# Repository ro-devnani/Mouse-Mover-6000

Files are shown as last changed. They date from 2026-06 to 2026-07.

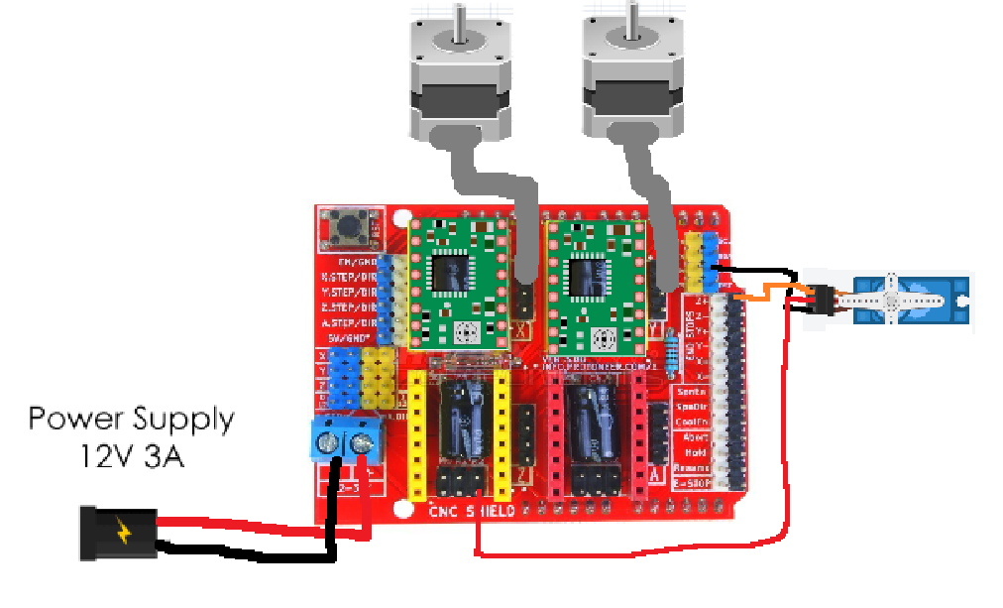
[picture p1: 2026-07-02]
images/mm6000 wiring diagram.png

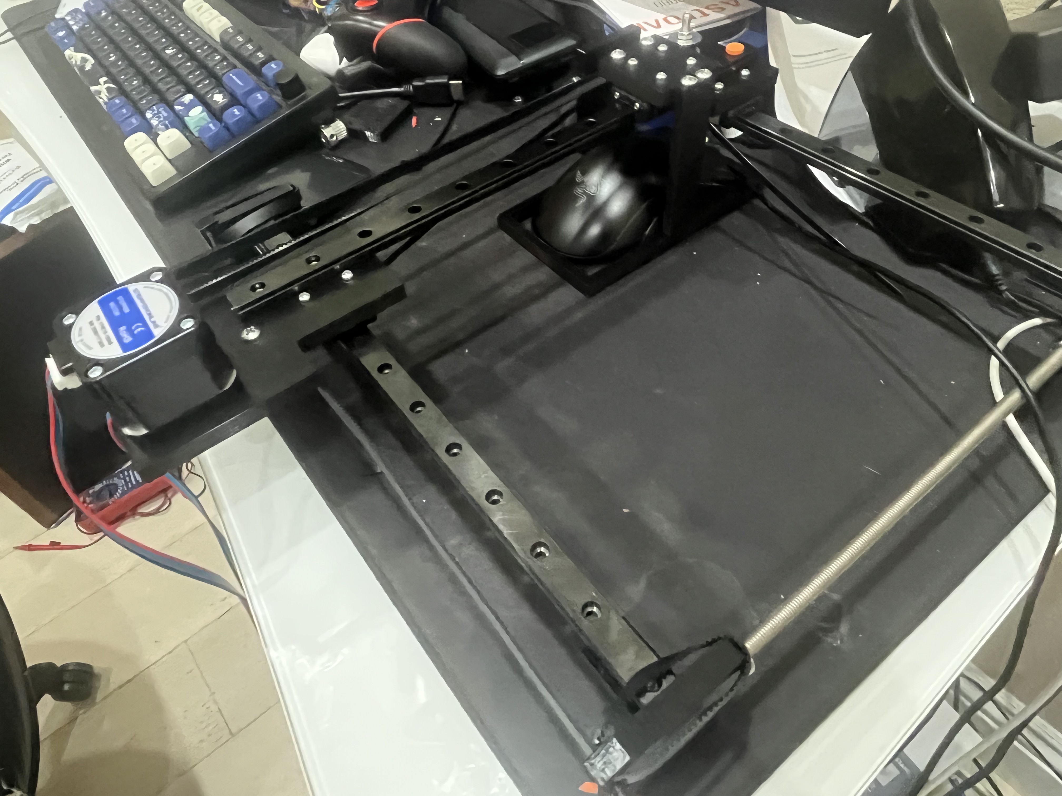
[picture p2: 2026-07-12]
images/IMG_5695.jpg

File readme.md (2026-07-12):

# _Mouse Mover 6000_
An XY plotter based system that can control the movement and clicks of your computer mouse in order to *help* one play shooter based video games by assisting aim.

## _Image Gallery_
mm6 image 1
mm6 image 5
mm6 image 2
mm6 image 3
mm6 image 4
mm6 detection code





## _How it Works_
A color-detection pipeline screenshots the display, finds the on-screen targets, and picks the one nearest the crosshair. The target's pixel offset from screen center is turned into a **velocity command** and streamed continuously over USB to an Arduino Uno + CNC Shield V3 running custom firmware (`code/firmware/mm6000_velocity/`).

The firmware runs the two NEMA 17 steppers at that commanded speed, ramping smoothly between updates instead of stopping every frame — so the mouse glides toward the target rather than moving in choppy hops. Once the crosshair is on the target, the SG90 servo clicks. Then it repeats for the next-nearest target.

> **Note:** the rig originally ran GRBL/G-code; that path was replaced by the custom velocity firmware. The old position-based (move-and-settle) driver is kept for reference in [`archive/stop-start-driver/`](archive/stop-start-driver/).

## _Setup & Run_
Steps to run on a fresh machine.

**1. Firmware** — open `code/firmware/mm6000_velocity/mm6000_velocity.ino` in the Arduino IDE, install the **AccelStepper** and **Servo** libraries, select the Uno + its port, and Upload. The Serial Monitor (115200 baud) should print `mm6000v ready`. Center the carriage before powering — power-on position is the origin.

Machine constants to check in the sketch before flashing:
```
STEPS_PER_MM_X/Y  5.0     // steps per mm — measure on your rig
SOFT_LIMIT_MM     90.0    // ± travel from the power-on origin
ACCEL             4000.0  // slew rate (higher = snappier, too high = jerky)
WATCHDOG_MS       600     // firmware ramps to 0 if the host goes quiet
```

**2. Python** —
```
cd code
pip install -r requirements.txt        # optional: pip install dxcam (faster capture)
```

**3. Configure** `code/aimplotter/config.py` — set `port` (your Arduino COM port), `screen_region`/`screen_center` for your display, and `hsv_lower`/`hsv_upper` for the target color.

**4. Calibrate `gain`** (mm of travel per pixel of view shift) — aim at a target and run:
```
python -m aimplotter.velocity_calibrate
```
Press ENTER; the carriage drives a known velocity for a known time, measures the pixel shift, and prints a suggested `config.gain`. Put that value in `config.py`.

**5. Dry-run** (no hardware, prints commands) then the real run:
```
python -m aimplotter.velocity_main --no-serial
python -m aimplotter.velocity_main
```
Kill switch: **`q`** (global). Teardown zeroes velocity and releases the servo.

**Tuning** (all in `config.py`, no reflash): `kp_v` = chase strength (raise for faster, lower if it overshoots), `max_speed_mm_s` = speed cap, `vel_deadzone_tol_px` = how tightly it centers before clicking. `kff` (feedforward) is off by default — at high frame rates it amplifies detection noise.

## _Bill of Materials_
I will be buying the few materials I need out of pocket, however these are the required components to reproduce.

| Item Name | Quantity | Price (Est. USD) | Link to Buy |
| :--- | :---: | :---: | :--- |
| **MGN12H Linear Guide Rails (300mm length with carriage block)** | 3 | $60.00 ($20.00 each) | [Amazon](https://www.amazon.com/s?k=MGN12H+300mm+linear+rail) / [AliExpress](https://www.aliexpress.com/w/wholesale-MGN12H-300mm.html) |
| **Arduino Uno R3 + CNC Shield V3 + A4988/TMC2208 Driver Bundle** | 1 | $22.00 | [Amazon](https://www.amazon.com/s?k=Arduino+Uno+CNC+Shield+V3+bundle) / [AliExpress](https://www.aliexpress.com/w/wholesale-Arduino+Uno+CNC+Shield+bundle.html) |
| **NEMA 17 Stepper Motor (1.5A - 2.0A)** | 2 | $24.00 ($12.00 each) | [Amazon](https://www.amazon.com/s?k=NEMA+17+stepper+motor) / [Adafruit](https://www.adafruit.com/product/324) |
| **SG90 Micro Servo Motor** | 1 | $4.00 | [Amazon](https://www.amazon.com/s?k=SG90+micro+servo) / [Adafruit](https://www.adafruit.com/product/169) |
| **12V 3A DC Power Supply Adapter** | 1 | $10.00 | [Amazon](https://www.amazon.com/s?k=12v+3a+power+supply+barrel+jack) |
| **GT2 Timing Belt (6mm wide, 2-3 meters)** | 1 | $8.00 | [Amazon](https://www.amazon.com/s?k=GT2+timing+belt+6mm) |
| **GT2 20-Tooth Drive Pulleys (5mm bore)** | 2 | $5.00 ($2.50 each) | [Amazon](https://www.amazon.com/s?k=GT2+20T+pulley+5mm+bore) |
| **GT2 Idler Pulleys (with bearings)** | 2 | $4.00 ($2.00 each) | [Amazon](https://www.amazon.com/s?k=GT2+idler+pulley) |
| **PETG 3D Printer Filament (1kg Spool)** | 1 | $20.00 | [Amazon](https://www.amazon.com/s?k=PETG+filament+1kg) |
| **M3 & M5 Machine Screws and Nuts Assortment Box** | 1 | $13.00 | [Amazon](https://www.amazon.com/s?k=M3+M5+screw+assortment) |
| **Jumper Wires (Female-to-Female)** | 1 | $5.00 | [Amazon](https://www.amazon.com/s?k=female+to+female+jumper+wires) |
| **USB Type-A to Type-B Printer Cable** | 1 | $6.00 | [Amazon](https://www.amazon.com/s?k=usb+a+to+b+cable) |
| **ESTIMATED TOTAL PRICE** | **-** | **$181.00** | **-** |

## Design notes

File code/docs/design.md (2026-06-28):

# mm6000 — Closed-Loop Optical Aim Plotter (Design)

**Date:** 2026-06-28
**Status:** Approved design, pre-implementation

## 1. Summary

Detect neon-blue balls on a 1080p fullscreen Aim Labs feed and drive a GRBL XY
plotter — which carries a physical computer mouse — so the screen-center
crosshair lands on the nearest ball, then fire a servo to click. Because a mouse
produces *relative* input, the system is a **closed-loop proportional-derivative
(PD) visual servo**, not absolute positioning.

## 2. Control Model

The in-game crosshair is fixed at screen center; the view turns based on
accumulated mouse motion. There is no fixed map from plotter position to view
direction, so each frame the loop measures pixel error and commands a relative
move:

```
loop every frame:
  frame  = capture_screen()
  balls  = detect_blue(frame)                 # HSV threshold + contours
  if balls:
      target = nearest_to_center(balls)
      err_px = target.center - screen_center  # (dx, dy) pixels
      if |err_px| <= target.radius:           # crosshair inside hitbox
          click()                             # servo press/release
      else:
          move_mm = pd_control(err_px)        # px -> mm, clamped (glide)
          plotter.jog(move_mm)                # GRBL relative move
  else:
      drift_corrector.tick()                  # reclaim travel during dead time
```

### PD controller
`move = Kp·err + Kd·Δerr + Ki·∫err`, with `Ki = 0` by default (pure PD).
- `Kp` (proportional): main pull toward target; gain < 1 yields a smooth glide.
- `Kd` (derivative): brakes against overshoot on fast flicks.
- `Ki` (integral): available via config for full PID; off by default to avoid
  windup between discrete targets.
- Output is clamped to `MAX_MOVE_MM_PER_FRAME` (rate limit = the "glide").

### GAIN / calibration
`GAIN` = mm of plotter travel per pixel of view error — the number that closes
the loop. Folded into `Kp`. Seeded from a default; refined by `calibrate.py`,
which moves the plotter a known distance and measures the resulting view shift
in pixels.

## 3. Drift Corrector

The loop is relative and closed, so absolute view orientation is irrelevant —
only error-to-target matters. Frames with no ball visible (gaps between Aim Labs
spawns, and just after a click) are "dead time": moving the carriage then turns
the view harmlessly. So after `DRIFT_IDLE_FRAMES` consecutive no-target frames,
the drift corrector gently glides the carriage back toward bed-center (using the
absolute position tracked from accumulated jogs), reclaiming travel headroom.
Normal aiming resumes the moment a ball reappears. The soft-limit guard remains
the hard safety net for the no-lift constraint (see §6).

## 4. Components

Each module has one purpose and a clean interface.

- `capture.py` — fast screen grab via `mss`; returns a BGR frame. Region
  configurable (default full 1920×1080).
- `detector.py` — `detect_blue(frame) -> [Ball(cx, cy, r)]`. HSV range from
  config, morphological denoise, min-area filter.
- `targeting.py` — `nearest_to_center(balls, center) -> Ball`; pixel-error vector.
- `controller.py` — PD/PID math: `error_px -> clamped mm move`; hitbox click
  decision. Pure functions, no I/O.
- `plotter.py` — GRBL serial driver (`pyserial`): connect, `$J=` jog with
  ok-handshake, absolute-position tracking, soft-limit guard, click via
  configurable `PRESS_CMD` / `RELEASE_CMD`.
- `drift.py` — drift corrector (§3).
- `calibrate.py` — interactive pixel-per-mm gain measurement. Optional;
  defaults provided.
- `config.py` — all tunables (HSV range, Kp/Ki/Kd, GAIN, MAX_MOVE_MM_PER_FRAME,
  hitbox tolerance, port, baud=115200, click commands, soft limits, bed-center,
  DRIFT_IDLE_FRAMES, kill key).
- `main.py` — wires the loop; starts kill-switch listener.

## 5. Safety / Kill-Switch

- Global hotkey (default `Q`, via `pynput`) **and** corner-slam detection →
  instant halt: GRBL feed-hold (`!`), servo release, stop loop.
- Soft-limit guard: clamp + warn if a move would exceed configured travel.
- Dry-run mode (`--no-serial`): prints G-code instead of sending, for testing
  detection without hardware.

## 6. Known Constraint

A mouse fixed to a 2D plotter with no Z lift cannot be recentered without
turning the view, so net drift accumulates across many targets. Mitigations:
the drift corrector (§3) reclaims headroom during dead time; the soft-limit
guard pauses for manual re-center if a limit is still reached. Adding a Z servo
to lift the mouse later would enable true unconditional auto-recenter.

## 7. Testing

- Unit: `detector` against synthetic screenshots (blue circles on noise) —
  asserts centroids/radii within tolerance.
- Unit: `controller` math (error→mm, clamping, PD response, hitbox trigger) —
  pure, no hardware.
- Unit: `drift` position tracking and recenter direction.
- Integration: dry-run loop over a recorded clip, asserting the emitted G-code
  sequence.

## 8. Stack

Python 3 · `opencv-python` · `mss` · `numpy` · `pyserial` · `pynput`.
GRBL pre-flashed on the Arduino Uno + CNC Shield v3; servo on the spindle pin,
commanded over the same USB serial link.

## 9. Hardware Assumptions

- Controller: Arduino Uno + CNC Shield v3, GRBL, USB serial @ 115200.
- Click: servo connected to the Arduino, actuated by `PRESS_CMD`/`RELEASE_CMD`
  (default `M3 S1000` / `M5`).
- Steps/mm and exact work-area travel: placeholder defaults in config, to be
  set by the user later.
- Display: single 1080p monitor, Aim Labs fullscreen.

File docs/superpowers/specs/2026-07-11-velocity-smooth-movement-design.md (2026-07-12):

# Velocity-Based Smooth Movement — Design

**Date:** 2026-07-11
**Status:** Approved (design), pending implementation plan
**Branch:** direct-stepper-driver

## Problem

The current aim system moves choppily. Each frame runs a full stop-start cycle:

1. `main.run_loop` computes a clamped **position** delta from the PD controller.
2. `StepperPlotter.jog()` sends `J dx dy feed`; firmware `runMove()` **blocks**,
   running both steppers to their targets and **decelerating to zero every jog**
   (AccelStepper accel/decel curve per move).
3. Python **blocks** waiting for the `ok` ack.
4. `time.sleep(move_settle_s)` lets the view render.
5. Re-capture, repeat.

Motion is therefore move → halt → settle → move → halt. The steppers never carry
momentum between frames, and the mandatory decel-to-zero + settle produces visible
choppiness.

## Goal

Replace discrete position moves with **continuous velocity streaming**. The
controller maps pixel error to a target **velocity** (mm/s) per axis. Firmware runs
the steppers continuously at the commanded speed, non-blocking; each frame only
updates the setpoint. Steppers glide and ramp smoothly toward each new velocity,
never halting between frames. No settle sleep, no blocking ack-wait on motion.

## Non-Goals

- Not replacing the existing stop-start system. It stays intact and runnable as a
  fallback (`controller.py`, `plotter.py`, `main.py`, `mm6000.ino`, `calibrate.py`
  are untouched).
- Not changing detection, tracking, capture, or drift subsystems — reused as-is.
- Not rewriting calibration. `calibrate.py` still measures mm/px gain, which informs
  velocity-tuning defaults but is not on the hot path.

## Architecture

New files, parallel to the existing ones:

```
aimplotter/
  velocity_controller.py     # pixel error -> per-axis velocity (mm/s)
  velocity_plotter.py        # streams V commands, non-blocking
  velocity_main.py           # detect -> aim -> click loop, no settle/no block
firmware/mm6000_velocity/
  mm6000_velocity.ino        # continuous velocity command + watchdog
config.py                    # + velocity section (shared file, new fields)
```

Data flow per frame:

```
capture.grab
  -> detect_blue -> pick target (tracker/nearest)
     target is None      -> set_velocity(0, 0)   (drift reuse deferred)
     error in deadzone    -> set_velocity(0, 0); click if armed
     otherwise            -> v = controller.step(target, dt); set_velocity(v)
```

## Component 1 — Firmware (`mm6000_velocity.ino`)

Same CNC Shield V3 pin map, servo, and `!` abort semantics as `mm6000.ino`.

**Protocol:**

| Command | Meaning | Ack |
|---|---|---|
| `V <vx_mm_s> <vy_mm_s>\n` | set target velocity per axis | **none** (fire-and-forget) |
| `S <angle>\n` | servo angle (click) | `ok` |
| `!` | abort: zero target velocity | none |

`V` intentionally does **not** ack. Streaming velocity at frame rate cannot afford a
blocking round-trip per update; the whole point is to remove the ack-wait stall.

**Control loop (non-blocking, tight):**

- Store `targetSpeedX`, `targetSpeedY` (steps/s), set by the last `V`.
- Each `loop()` iteration:
  1. Drain any available serial bytes into the line buffer; parse complete lines.
  2. **Slew** `currentSpeedX/Y` toward `targetSpeedX/Y`, limited to `ACCEL * dt`
     steps/s per tick. Bounded acceleration = smooth ramps, no velocity-step jerk
     even if the setpoint jumps.
  3. `setSpeed(currentSpeed)` then `runSpeed()` for each axis (constant-speed step
     generation; no AccelStepper decel-to-target because there is no target).
- `dt` measured from `micros()` between iterations.

**Watchdog:** if no `V` command has arrived within `WATCHDOG_MS` (~200 ms), force
`targetSpeed = 0` on both axes. The slew still applies, so the rig ramps down smoothly
rather than snapping. Protects against a dead/unplugged host leaving the rig running.

**Soft limits (authoritative in firmware):** track `currentPosition()` in steps.
Convert `soft_limit_mm` to steps at compile/config time. Before `runSpeed()`, if an
axis is at or beyond its ± limit **and** the commanded velocity points further out,
zero that axis's speed (that axis only; the other keeps moving). Firmware is the
final authority on limits; Python keeps an estimate only for logging.

## Component 2 — Velocity controller (`velocity_controller.py`)

Pure function of pixel error + target motion; holds minimal state for feedforward.

```
v_axis = kp_v * error_px[axis] + kff * target_velocity_px_s[axis]
```

- `error_px` = target center − screen center (same sign convention as current
  `error_vector`; invert_x / invert_y applied as today).
- `target_velocity_px_s` = (target pixel position − previous target pixel position)
  / dt. Feedforward term: keeps the crosshair with a moving target instead of always
  chasing from behind.
- **Deadzone:** if `hypot(error) <= radius + vel_deadzone_tol_px`, output `(0, 0)`
  and signal "on target" so the caller can hold and arm/fire the click.
- **Clamp:** limit `hypot(vx, vy)` to `max_speed_mm_s` (preserve direction).
- **State:** previous target pixel position + previous timestamp. `reset()` clears
  it (call when the locked target changes, so feedforward does not jump across a
  target switch). If no previous sample, feedforward is 0 for that frame.

Units: `kp_v` is mm/s of commanded speed per pixel of error. `kff` is dimensionless
scaling on target pixel velocity converted to mm/s via the calibrated mm/px gain
(so `kff = 1.0` means "match the target's apparent speed"). Default `kff` starts
conservative.

## Component 3 — Velocity plotter (`velocity_plotter.py`)

```
set_velocity(vx_mm_s, vy_mm_s) -> None   # sends "V vx vy\n", NO ack-wait
click() -> None                          # S press, dwell, S release (ack)
safe_stop() -> None                      # S release, then "!"
feed_hold() -> None                      # "!"
position (property) -> (x, y)            # estimate from integrated velocity*dt
```

- `set_velocity` writes and returns immediately — this is the streaming hot path.
- `click`/`safe_stop` reuse the acked `S` path from the existing plotter design.
- Position estimate is for debug/logging only; firmware enforces limits. Plotter may
  still pre-clamp the commanded velocity toward a limit as a courtesy, but is not the
  authority.

## Component 4 — Velocity main (`velocity_main.py`)

Mirrors `main.run_loop` structure minus the blocking bits:

- No `move_settle_s` sleep. No per-move ack stall. Loop cadence = capture cadence.
- Compute `dt` between frames (for controller feedforward + firmware watchdog health).
- Same kill-switch listener and `_PrintPlotter` dry-run (prints `V`/`CLICK`).
- On target-in-deadzone: `set_velocity(0, 0)`; `click()` if armed; then hold (no jog).
  Re-arm when the crosshair leaves the target, same as current `armed` logic.
- On no target: `set_velocity(0, 0)`. Drift reuse is optional and deferred; the
  velocity system's baseline is "stop when nothing to track."
- On teardown (`finally`): `set_velocity(0, 0)` then `safe_stop()`.

## Component 5 — Config additions

Append a velocity section to the existing `Config` dataclass (reusing detection,
capture, serial, soft-limit, servo fields). New fields:

| Field | Purpose | Starting default |
|---|---|---|
| `kp_v` | mm/s commanded per px error | tune (e.g. 0.05) |
| `kff` | feedforward scale on target motion | 0.5 |
| `max_speed_mm_s` | velocity magnitude clamp | e.g. 40 |
| `vel_watchdog_ms` | host-side note; firmware constant mirrors it | 200 |
| `vel_deadzone_tol_px` | hold zone = radius + this | 6.0 |

Existing stop-start fields (`gain`, `kp/ki/kd`, `max_move_mm`, `move_settle_s`) are
left untouched so the old system still runs.

## Error Handling & Safety

- **Firmware watchdog** ramps to zero if the host stops streaming — primary safety net.
- **`!` abort** and the kill-switch key remain wired through.
- **Soft limits** enforced in firmware (authoritative), estimated in Python.
- Malformed `V` line: firmware ignores (no target change) rather than faulting; the
  watchdog covers a persistent parse failure.

## Testing

- **Controller** — pure/unit testable: feed synthetic error + target-motion sequences,
  assert velocity output, deadzone zeroing, clamp magnitude, feedforward reset on
  target switch. No hardware.
- **Plotter** — inject a fake serial object; assert exact `V`/`S`/`!` bytes and that
  `set_velocity` does not block on a read.
- **Main loop** — reuse the existing `run_loop` test harness pattern (frame source
  callable + fake plotter), assert the action log: `vel`, `hold`, `click`, `idle`.
- **Firmware** — manual/bench: confirm continuous motion, smooth ramp on setpoint
  jumps, watchdog stop on host silence, per-axis limit clamp.

## Open Questions (resolve during planning)

- Exact starting values for `kp_v` / `kff` / `max_speed_mm_s` (bench-tune; spec gives
  conservative seeds).
- Whether to reuse `DriftCorrector` in velocity mode or keep "stop when idle" only.
```

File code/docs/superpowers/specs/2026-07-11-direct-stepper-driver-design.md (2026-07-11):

# Direct Stepper Driver — Replace GRBL with Custom Firmware (Design)

**Date:** 2026-07-11
**Status:** Approved design, pre-implementation

## 1. Summary

Remove GRBL from the Arduino Uno. Use the CNC Shield V3 as a passive breakout
board and run custom firmware that drives the A4988 STEP/DIR pins directly and
actuates the SG90 click servo. The PC talks to the firmware over a simple
line-based serial protocol.

The existing Python control stack (screen capture → blue detection → nearest
target → PD controller → relative jog → servo click, plus drift corrector and
kill-switch) is unchanged in behaviour. Only the plotter **driver internals**
and a few `config.py` fields change, because the Python↔hardware seam keeps the
same shape it has today: send a line, wait for `ok`.

## 2. Motivation

GRBL adds a firmware layer whose CNC semantics (jog queue, laser/spindle modes,
homing, `$$` config) are overhead for this project and introduced real setup
snags — notably driving a hobby servo off the ~1 kHz spindle PWM pin. Owning the
firmware lets us drive the servo with the `Servo` library at the correct 50 Hz
and keep the motion model as simple as the task needs (relative jogs, no
homing, no endstops).

## 3. Architecture

Two halves connected by a serial line protocol. The seam is identical to the
current design, so the Python loop above the driver is untouched.

```
PC (Python)                              Arduino Uno + CNC Shield V3
-----------                              ---------------------------
StepperPlotter.jog(dx,dy)  --"J dx dy feed\n"-->  parse, mm->steps,
                                                  AccelStepper run, then
                           <------"ok\n"--------  ack
StepperPlotter.click()     --"S 60\n"--------->   servo.write(60), ack
                              (dwell)
                           --"S 90\n"--------->   servo.write(90), ack
StepperPlotter.safe_stop() --"!"------------->    abort motion (no ack)
```

### 3.1 Firmware — `firmware/mm6000/mm6000.ino`

- **CNC Shield V3 is a passive breakout.** Standard GRBL pin map:
  - X: STEP=D2, DIR=D5
  - Y: STEP=D3, DIR=D6
  - Driver ENABLE=D8 (active low; pulled LOW at boot to energize drivers)
  - Servo signal=D11
- **Libraries:** `AccelStepper` (one instance per axis) and `Servo`.
- **Compile-time constants (`#define`):** `STEPS_PER_MM_X`, `STEPS_PER_MM_Y`,
  `ACCEL` (steps/s²), `DEFAULT_SPEED` (steps/s fallback). `steps/mm` lives here,
  measured on the built machine and baked in; changing microstepping means a
  reflash.
- **Motion:** each axis is an `AccelStepper` in `DRIVER` mode. A move sets both
  axes' `maxSpeed` from the requested feed, calls `moveTo` (relative target in
  steps), then loops `run()` on both until both reach target. Acceleration is
  applied per axis. The two axes are not guaranteed to finish the same instant;
  for the ≤5 mm per-frame jogs the skew is negligible (accepted trade-off — the
  coordinated alternative, `MultiStepper`, cannot do acceleration).
- **Abort:** the run loop polls `Serial.available()` every iteration. If a `!`
  byte arrives mid-move, it stops both steppers immediately and exits the move.
  This keeps kill-switch latency low even though normal moves block.
- **Boot:** set ENABLE low, attach servo, move servo to release angle, print a
  ready banner. Then serve the command loop.

### 3.2 Serial protocol

- 115200 baud, `\n`-terminated ASCII lines. Every completed command replies
  `ok\n`. Unknown commands reply `err\n`.

| PC → Arduino | Meaning | Reply |
| :--- | :--- | :--- |
| `J <dx_mm> <dy_mm> <feed_mm_min>` | Relative move. Firmware converts mm→steps, sets max speed from feed, runs to completion. | `ok` after move done |
| `S <angle>` | Set servo to `<angle>` degrees (0–180). | `ok` |
| `!` (single byte, **no** newline) | Realtime abort — stop steppers now. | none |

Design intent: mirror the current "send line, wait for `ok`" handshake so
`StepperPlotter._send` is the same shape as today's `GRBLPlotter._send`.

### 3.3 Python — `aimplotter/plotter.py`

Rename `GRBLPlotter` → `StepperPlotter`. Identical public surface:

- `__init__(serial_obj, soft_limit_mm, bed_center_mm, press_angle,
  release_angle, click_dwell_s, feed_mm_min=3000, sleep_fn=time.sleep)`
- `position -> tuple[float, float]` — unchanged (tracked from accumulated jogs).
- `jog(dx_mm, dy_mm) -> bool` — keeps the existing soft-limit `_clamp` (the only
  travel guard; no endstops are wired). Sends `J <real_dx> <real_dy> <feed>\n`,
  waits for `ok`, updates tracked position, returns `False` if clamped.
- `click()` — sends `S <press_angle>\n`, sleeps `click_dwell_s`, sends
  `S <release_angle>\n`.
- `feed_hold()` / `safe_stop()` — write the raw `!` byte.

`_send` writes the line, then reads lines until `ok` (raising `RuntimeError` on
`err`), matching the current ok-handshake loop.

### 3.4 Config — `aimplotter/config.py`

- Remove `press_cmd`, `release_cmd`.
- Add `press_angle: int = 60`, `release_angle: int = 90` (tune to servo horn).
- `port`, `baud` (115200), soft limits, everything else unchanged.
- `steps/mm` is **not** in Python config — it lives in firmware.

### 3.5 Wiring — `main.py`, `calibrate.py`

Only the `StepperPlotter` constructor call changes: pass `config.press_angle` /
`config.release_angle` instead of the old M-code strings. Loop, controller,
drift, capture, kill-switch untouched.

## 4. Data Flow (unchanged above the driver)

`capture → detect_blue → nearest_to_center → PDController.step → StepperPlotter.jog`
per frame; on hitbox hit → `StepperPlotter.click`; on dead frames →
`DriftCorrector.tick → StepperPlotter.jog`. The GAIN (mm-per-pixel) calibration
via `calibrate.py` is unaffected — it still jogs a known mm and measures pixel
shift.

## 5. Error Handling & Safety

- **Soft-limit clamp** in `jog()` stays the sole travel guard (no endstops).
- **Kill switch:** `q` stops the Python loop; `finally` calls `safe_stop()` →
  `!`. Firmware aborts mid-move on `!`.
- **Serial errors:** `_send` raises `RuntimeError` on `err` reply; `main.py`
  swallows exceptions in the `finally` cleanup path as today.
- **Boot settle:** `main.py` keeps the ~2 s sleep after opening serial so the
  Uno finishes resetting before the first command.

## 6. Testing

- `tests/test_plotter.py` rewritten against a `FakeSerial` that acks `ok\n`:
  - `jog` sends a line starting `J ` with correct `X`/`Y`… → assert on the `J`
    payload and tracked position (adapt existing format assertions).
  - `jog` clamps to soft limits and returns `False` beyond travel (unchanged
    logic, unchanged assertion).
  - `click` sends `S <press_angle>` then `S <release_angle>`.
  - `safe_stop`/`feed_hold` write the raw `!` byte.
- All other unit tests (detector, targeting, controller, drift) and the
  integration test are unaffected — they never touch the serial protocol.
- Firmware is verified manually on hardware (jog a known distance, confirm servo
  press/release); no automated firmware test.

## 7. Files Touched

- Create: `firmware/mm6000/mm6000.ino`
- Edit: `aimplotter/plotter.py` (class rename + new protocol)
- Edit: `aimplotter/config.py` (angles replace M-codes)
- Edit: `aimplotter/main.py` (constructor args)
- Edit: `aimplotter/calibrate.py` (constructor args)
- Edit: `tests/test_plotter.py` (protocol assertions)

## 8. Out of Scope

- Homing / endstops (none wired).
- Coordinated same-instant multi-axis finish (accepted skew).
- Runtime-configurable steps/mm (reflash instead).
- Z-lift servo for true auto-recenter (future, as noted in prior design §6).

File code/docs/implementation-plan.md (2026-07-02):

# Closed-Loop Optical Aim Plotter Implementation Plan

**Goal:** Detect neon-blue balls on a 1080p fullscreen Aim Labs feed and drive a GRBL XY plotter (carrying a physical mouse) via a closed-loop PD visual servo so the screen-center crosshair lands on the nearest ball and clicks.

**Architecture:** A per-frame loop: capture screen → HSV-detect balls → pick nearest to center → PD controller turns pixel error into a clamped relative mm jog → GRBL serial driver moves the plotter → repeat until the crosshair is inside the ball's hitbox → servo click. A drift corrector reclaims plotter travel during no-target frames. Pure logic modules (detector, targeting, controller, drift) are hardware-free and unit-tested; the plotter driver is tested against a fake serial port.

**Tech Stack:** Python 3 · `opencv-python` · `numpy` · `mss` · `pyserial` · `pynput` · `pytest`

## Global Constraints

- Python 3.10+ (uses `X | None` typing, `match` optional).
- Target display: single 1920×1080 monitor; crosshair fixed at screen center `(960, 540)`.
- GRBL on Arduino Uno + CNC Shield v3, USB serial @ **115200** baud.
- Plotter moves are **relative** (`G91`) via GRBL jog (`$J=`); each line waits for `ok`.
- Click is firmware-agnostic: configurable `PRESS_CMD` / `RELEASE_CMD` strings (default `M3 S1000` / `M5`).
- All tunables live in `config.py`; no magic numbers in logic modules — pass config values in as parameters (keep logic modules pure).
- Distances in millimetres (mm); pixel errors in pixels (px). `GAIN` = mm per px.
- Steps/mm and exact work-area travel are user-set later; use placeholder defaults.
- Every logic module is hardware-free and importable without a serial port attached.

---

## File Structure

```
mm6000/
├── requirements.txt
├── aimplotter/
│   ├── __init__.py
│   ├── config.py          # Config dataclass, all tunables + defaults
│   ├── models.py          # Ball dataclass
│   ├── detector.py        # detect_blue()
│   ├── targeting.py       # nearest_to_center(), error_vector()
│   ├── controller.py      # PDController (PD/PID), on_target()
│   ├── plotter.py         # GRBLPlotter serial driver
│   ├── drift.py           # DriftCorrector
│   ├── capture.py         # ScreenCapture (mss)
│   ├── calibrate.py       # interactive GAIN measurement (script)
│   └── main.py            # loop wiring + kill-switch + dry-run
└── tests/
    ├── test_detector.py
    ├── test_targeting.py
    ├── test_controller.py
    ├── test_plotter.py
    ├── test_drift.py
    └── test_integration.py
```

---

### Task 1: Project scaffold, config, and Ball model

**Files:**
- Create: `requirements.txt`
- Create: `aimplotter/__init__.py`
- Create: `aimplotter/config.py`
- Create: `aimplotter/models.py`
- Test: `tests/test_targeting.py` (placeholder import test here; real tests in Task 3)

**Interfaces:**
- Produces: `Ball(cx: float, cy: float, r: float)` dataclass with `center -> tuple[float, float]`.
- Produces: `Config` dataclass with fields used by all later tasks (see code).

- [ ] **Step 1: Write `requirements.txt`**

```
opencv-python>=4.8
numpy>=1.24
mss>=9.0
pyserial>=3.5
pynput>=1.7
pytest>=7.4
```

- [ ] **Step 2: Write `aimplotter/__init__.py`** (empty file)

```python
```

- [ ] **Step 3: Write the failing test for the models**

`tests/test_targeting.py`:
```python
from aimplotter.models import Ball
from aimplotter.config import Config

def test_ball_center():
    b = Ball(cx=10.0, cy=20.0, r=5.0)
    assert b.center == (10.0, 20.0)

def test_config_defaults():
    c = Config()
    assert c.baud == 115200
    assert c.screen_center == (960, 540)
    assert c.ki == 0.0  # pure PD by default
```

- [ ] **Step 4: Run test to verify it fails**

Run: `python -m pytest tests/test_targeting.py -v`
Expected: FAIL with `ModuleNotFoundError: No module named 'aimplotter.models'`

- [ ] **Step 5: Write `aimplotter/models.py`**

```python
from dataclasses import dataclass

@dataclass
class Ball:
    cx: float
    cy: float
    r: float

    @property
    def center(self) -> tuple[float, float]:
        return (self.cx, self.cy)
```

- [ ] **Step 6: Write `aimplotter/config.py`**

```python
from dataclasses import dataclass, field

@dataclass
class Config:
    # --- display ---
    screen_region: dict = field(
        default_factory=lambda: {"top": 0, "left": 0, "width": 1920, "height": 1080}
    )
    screen_center: tuple[int, int] = (960, 540)

    # --- detection (neon blue in HSV; OpenCV H is 0-179) ---
    hsv_lower: tuple[int, int, int] = (90, 120, 120)
    hsv_upper: tuple[int, int, int] = (120, 255, 255)
    min_area_px: float = 80.0

    # --- control ---
    gain: float = 0.03            # mm of plotter travel per px of error
    kp: float = 1.0               # multiplies gain
    ki: float = 0.0               # 0 = pure PD
    kd: float = 0.2
    max_move_mm: float = 5.0      # clamp per frame -> "glide"
    hitbox_tol_px: float = 6.0    # extra slack added to ball radius

    # --- plotter / serial ---
    port: str = "COM3"
    baud: int = 115200
    press_cmd: str = "M3 S1000"
    release_cmd: str = "M5"
    click_dwell_s: float = 0.04

    # --- soft limits (mm), bed center is origin reference ---
    soft_limit_mm: float = 100.0  # +/- travel from start in X and Y
    bed_center_mm: tuple[float, float] = (0.0, 0.0)

    # --- drift corrector ---
    drift_idle_frames: int = 8
    drift_step_mm: float = 1.0

    # --- safety ---
    kill_key: str = "q"
```

- [ ] **Step 7: Run tests to verify they pass**

Run: `python -m pytest tests/test_targeting.py -v`
Expected: PASS (2 passed)

- [ ] **Step 8: Commit**

```bash
git add requirements.txt aimplotter/__init__.py aimplotter/models.py aimplotter/config.py tests/test_targeting.py
git commit -m "feat: project scaffold, Config, and Ball model"
```

---

### Task 2: Blue-ball detector

**Files:**
- Create: `aimplotter/detector.py`
- Test: `tests/test_detector.py`

**Interfaces:**
- Consumes: `Ball` (Task 1).
- Produces: `detect_blue(frame, hsv_lower, hsv_upper, min_area) -> list[Ball]` where `frame` is an HxWx3 BGR `numpy.uint8` array; returns balls sorted by descending area.

- [ ] **Step 1: Write the failing test**

`tests/test_detector.py`:
```python
import numpy as np
import cv2
from aimplotter.detector import detect_blue
from aimplotter.config import Config

C = Config()

def _frame_with_blue_circle(cx, cy, r, size=(1080, 1920)):
    frame = np.zeros((size[0], size[1], 3), dtype=np.uint8)
    # neon blue in BGR is high B, low G/R
    cv2.circle(frame, (cx, cy), r, (255, 80, 0), -1)
    return frame

def test_detects_single_ball_center():
    frame = _frame_with_blue_circle(960, 540, 30)
    balls = detect_blue(frame, C.hsv_lower, C.hsv_upper, C.min_area_px)
    assert len(balls) == 1
    assert abs(balls[0].cx - 960) <= 3
    assert abs(balls[0].cy - 540) <= 3
    assert balls[0].r > 20

def test_ignores_small_noise():
    frame = _frame_with_blue_circle(100, 100, 2)
    balls = detect_blue(frame, C.hsv_lower, C.hsv_upper, C.min_area_px)
    assert balls == []

def test_detects_multiple_sorted_by_area():
    frame = _frame_with_blue_circle(300, 300, 20)
    cv2.circle(frame, (1500, 800), 40, (255, 80, 0), -1)
    balls = detect_blue(frame, C.hsv_lower, C.hsv_upper, C.min_area_px)
    assert len(balls) == 2
    assert balls[0].r >= balls[1].r  # largest first
```

- [ ] **Step 2: Run test to verify it fails**

Run: `python -m pytest tests/test_detector.py -v`
Expected: FAIL with `ModuleNotFoundError: No module named 'aimplotter.detector'`

- [ ] **Step 3: Write `aimplotter/detector.py`**

```python
import cv2
import numpy as np
from aimplotter.models import Ball

def detect_blue(frame, hsv_lower, hsv_upper, min_area) -> list[Ball]:
    """Find neon-blue blobs in a BGR frame, return Balls sorted largest-first."""
    hsv = cv2.cvtColor(frame, cv2.COLOR_BGR2HSV)
    mask = cv2.inRange(hsv, np.array(hsv_lower), np.array(hsv_upper))
    kernel = np.ones((3, 3), np.uint8)
    mask = cv2.morphologyEx(mask, cv2.MORPH_OPEN, kernel)
    mask = cv2.morphologyEx(mask, cv2.MORPH_CLOSE, kernel)

    contours, _ = cv2.findContours(mask, cv2.RETR_EXTERNAL, cv2.CHAIN_APPROX_SIMPLE)
    balls: list[Ball] = []
    for c in contours:
        area = cv2.contourArea(c)
        if area < min_area:
            continue
        (x, y), r = cv2.minEnclosingCircle(c)
        balls.append(Ball(cx=float(x), cy=float(y), r=float(r)))

    balls.sort(key=lambda b: b.r, reverse=True)
    return balls
```

- [ ] **Step 4: Run tests to verify they pass**

Run: `python -m pytest tests/test_detector.py -v`
Expected: PASS (3 passed)

- [ ] **Step 5: Commit**

```bash
git add aimplotter/detector.py tests/test_detector.py
git commit -m "feat: HSV neon-blue ball detector"
```

---

### Task 3: Targeting

**Files:**
- Create: `aimplotter/targeting.py`
- Test: `tests/test_targeting.py` (extend)

**Interfaces:**
- Consumes: `Ball` (Task 1).
- Produces:
  - `nearest_to_center(balls, center) -> Ball | None`
  - `error_vector(ball, center) -> tuple[float, float]` returning `(dx, dy)` = ball − center.

- [ ] **Step 1: Write the failing tests** (append to `tests/test_targeting.py`)

```python
from aimplotter.targeting import nearest_to_center, error_vector

def test_nearest_to_center_picks_closest():
    near = Ball(cx=965.0, cy=545.0, r=10.0)
    far = Ball(cx=200.0, cy=200.0, r=10.0)
    assert nearest_to_center([far, near], (960, 540)) is near

def test_nearest_to_center_empty_returns_none():
    assert nearest_to_center([], (960, 540)) is None

def test_error_vector():
    b = Ball(cx=1000.0, cy=500.0, r=10.0)
    assert error_vector(b, (960, 540)) == (40.0, -40.0)
```

- [ ] **Step 2: Run tests to verify they fail**

Run: `python -m pytest tests/test_targeting.py -v`
Expected: FAIL with `ModuleNotFoundError: No module named 'aimplotter.targeting'`

- [ ] **Step 3: Write `aimplotter/targeting.py`**

```python
import math
from aimplotter.models import Ball

def error_vector(ball: Ball, center) -> tuple[float, float]:
    return (ball.cx - center[0], ball.cy - center[1])

def nearest_to_center(balls, center) -> Ball | None:
    if not balls:
        return None
    return min(
        balls,
        key=lambda b: math.hypot(b.cx - center[0], b.cy - center[1]),
    )
```

- [ ] **Step 4: Run tests to verify they pass**

Run: `python -m pytest tests/test_targeting.py -v`
Expected: PASS (5 passed)

- [ ] **Step 5: Commit**

```bash
git add aimplotter/targeting.py tests/test_targeting.py
git commit -m "feat: nearest-target selection and error vector"
```

---

### Task 4: PD/PID controller

**Files:**
- Create: `aimplotter/controller.py`
- Test: `tests/test_controller.py`

**Interfaces:**
- Produces:
  - `PDController(gain, kp, ki, kd, max_move_mm)` with `step(err_px) -> tuple[float, float]` (clamped mm move) and `reset()`.
  - `on_target(err_px, radius, tol) -> bool` — True when the crosshair is inside the hitbox.
- Consumes: config scalars (Task 1).

Note: `step` takes `err_px=(dx, dy)`; output mm has the **same sign** as error (move toward target). Magnitude clamped to `max_move_mm`. Derivative uses change in error between calls.

- [ ] **Step 1: Write the failing tests**

`tests/test_controller.py`:
```python
import math
from aimplotter.controller import PDController, on_target

def test_proportional_move_toward_target():
    c = PDController(gain=0.03, kp=1.0, ki=0.0, kd=0.0, max_move_mm=5.0)
    mx, my = c.step((100.0, -100.0))
    assert mx > 0 and my < 0                 # same direction as error
    assert math.isclose(mx, 3.0, abs_tol=1e-6)   # 100 * 0.03 * 1.0

def test_move_is_clamped():
    c = PDController(gain=1.0, kp=1.0, ki=0.0, kd=0.0, max_move_mm=5.0)
    mx, my = c.step((100.0, 0.0))
    assert math.isclose(math.hypot(mx, my), 5.0, abs_tol=1e-6)

def test_derivative_damps_on_growing_error():
    c = PDController(gain=0.0, kp=0.0, ki=0.0, kd=0.5, max_move_mm=100.0)
    c.step((10.0, 0.0))            # prev err set
    mx, _ = c.step((30.0, 0.0))    # delta = 20 -> 0.5*20 = 10
    assert math.isclose(mx, 10.0, abs_tol=1e-6)

def test_reset_clears_state():
    c = PDController(gain=0.0, kp=0.0, ki=0.0, kd=0.5, max_move_mm=100.0)
    c.step((10.0, 0.0))
    c.reset()
    mx, _ = c.step((10.0, 0.0))    # treated as first sample, delta=0
    assert math.isclose(mx, 0.0, abs_tol=1e-6)

def test_on_target_inside_hitbox():
    assert on_target((3.0, 0.0), radius=10.0, tol=2.0) is True
    assert on_target((20.0, 0.0), radius=10.0, tol=2.0) is False
```

- [ ] **Step 2: Run tests to verify they fail**

Run: `python -m pytest tests/test_controller.py -v`
Expected: FAIL with `ModuleNotFoundError: No module named 'aimplotter.controller'`

- [ ] **Step 3: Write `aimplotter/controller.py`**

```python
import math

class PDController:
    """Turns a pixel-error vector into a clamped relative mm move.

    Pure PD by default (ki=0); set ki>0 for full PID. State held between
    step() calls for derivative/integral terms; reset() between targets.
    """

    def __init__(self, gain, kp, ki, kd, max_move_mm):
        self.gain = gain
        self.kp = kp
        self.ki = ki
        self.kd = kd
        self.max_move_mm = max_move_mm
        self.reset()

    def reset(self) -> None:
        self._prev = None
        self._integral = [0.0, 0.0]

    def step(self, err_px) -> tuple[float, float]:
        out = [0.0, 0.0]
        for i in range(2):
            e = err_px[i]
            d = 0.0 if self._prev is None else (e - self._prev[i])
            self._integral[i] += e
            term = self.kp * e + self.kd * d + self.ki * self._integral[i]
            out[i] = self.gain * term
        self._prev = (err_px[0], err_px[1])

        mag = math.hypot(out[0], out[1])
        if mag > self.max_move_mm and mag > 0:
            scale = self.max_move_mm / mag
            out[0] *= scale
            out[1] *= scale
        return (out[0], out[1])

def on_target(err_px, radius, tol) -> bool:
    return math.hypot(err_px[0], err_px[1]) <= (radius + tol)
```

- [ ] **Step 4: Run tests to verify they pass**

Run: `python -m pytest tests/test_controller.py -v`
Expected: PASS (5 passed)

- [ ] **Step 5: Commit**

```bash
git add aimplotter/controller.py tests/test_controller.py
git commit -m "feat: PD/PID controller and hitbox check"
```

---

### Task 5: GRBL serial plotter driver

**Files:**
- Create: `aimplotter/plotter.py`
- Test: `tests/test_plotter.py`

**Interfaces:**
- Produces: `GRBLPlotter(serial_obj, soft_limit_mm, bed_center_mm, press_cmd, release_cmd, click_dwell_s)` with:
  - `jog(dx_mm, dy_mm) -> bool` — sends `$J=G91 G21 X.. Y.. F..`, waits `ok`, updates tracked position, clamps to soft limits (returns `False` if clamped).
  - `click()` — sends press_cmd, dwell, release_cmd.
  - `feed_hold()` — sends `!`.
  - `position -> tuple[float, float]` — tracked absolute mm from start.
  - `sleep_fn` injectable (defaults to `time.sleep`) so tests don't actually wait.
- The serial object must expose `write(bytes)` and `readline() -> bytes`. Tests pass a `FakeSerial` that returns `b"ok\n"`.

- [ ] **Step 1: Write the failing tests**

`tests/test_plotter.py`:
```python
from aimplotter.plotter import GRBLPlotter

class FakeSerial:
    def __init__(self):
        self.written = []
        self._lines = []

    def write(self, data):
        self.written.append(data.decode())
        self._lines.append(b"ok\n")  # GRBL acks every line

    def readline(self):
        return self._lines.pop(0) if self._lines else b"ok\n"

def _plotter():
    return GRBLPlotter(
        FakeSerial(), soft_limit_mm=10.0, bed_center_mm=(0.0, 0.0),
        press_cmd="M3 S1000", release_cmd="M5", click_dwell_s=0.0,
        sleep_fn=lambda s: None,
    )

def test_jog_sends_relative_gcode_and_tracks_position():
    p = _plotter()
    ok = p.jog(2.0, -1.5)
    assert ok is True
    assert p.position == (2.0, -1.5)
    sent = p.serial.written[-1]
    assert sent.startswith("$J=G91 G21")
    assert "X2.000" in sent and "Y-1.500" in sent

def test_jog_clamps_to_soft_limits():
    p = _plotter()
    ok = p.jog(50.0, 0.0)            # beyond +10 limit
    assert ok is False
    assert p.position[0] == 10.0     # clamped to limit

def test_click_sends_press_then_release():
    p = _plotter()
    p.click()
    assert "M3 S1000" in p.serial.written[-2]
    assert "M5" in p.serial.written[-1]

def test_feed_hold_sends_bang():
    p = _plotter()
    p.feed_hold()
    assert p.serial.written[-1] == "!"
```

- [ ] **Step 2: Run tests to verify they fail**

Run: `python -m pytest tests/test_plotter.py -v`
Expected: FAIL with `ModuleNotFoundError: No module named 'aimplotter.plotter'`

- [ ] **Step 3: Write `aimplotter/plotter.py`**

```python
import time

class GRBLPlotter:
    def __init__(self, serial_obj, soft_limit_mm, bed_center_mm,
                 press_cmd, release_cmd, click_dwell_s,
                 feed_mm_min=3000, sleep_fn=time.sleep):
        self.serial = serial_obj
        self.soft_limit_mm = soft_limit_mm
        self.center = bed_center_mm
        self.press_cmd = press_cmd
        self.release_cmd = release_cmd
        self.click_dwell_s = click_dwell_s
        self.feed_mm_min = feed_mm_min
        self._sleep = sleep_fn
        self._x, self._y = bed_center_mm

    @property
    def position(self) -> tuple[float, float]:
        return (self._x, self._y)

    def _send(self, line: str) -> None:
        self.serial.write(line.encode() if not line.endswith("\n")
                          else line.encode())
        self.serial.readline()  # wait for GRBL 'ok'

    def _clamp(self, target, axis_center):
        lo = axis_center - self.soft_limit_mm
        hi = axis_center + self.soft_limit_mm
        if target < lo:
            return lo, True
        if target > hi:
            return hi, True
        return target, False

    def jog(self, dx_mm, dy_mm) -> bool:
        nx, cx_clamped = self._clamp(self._x + dx_mm, self.center[0])
        ny, cy_clamped = self._clamp(self._y + dy_mm, self.center[1])
        real_dx = nx - self._x
        real_dy = ny - self._y
        line = (f"$J=G91 G21 X{real_dx:.3f} Y{real_dy:.3f} "
                f"F{self.feed_mm_min}\n")
        self._send(line)
        self._x, self._y = nx, ny
        return not (cx_clamped or cy_clamped)

    def click(self) -> None:
        self._send(self.press_cmd + "\n")
        self._sleep(self.click_dwell_s)
        self._send(self.release_cmd + "\n")

    def feed_hold(self) -> None:
        self.serial.write(b"!")  # realtime, no newline, no ok
```

Note: `feed_hold` writes the raw `!` byte (GRBL realtime command — no newline, no `ok`). The test asserts `written[-1] == "!"`.

- [ ] **Step 4: Run tests to verify they pass**

Run: `python -m pytest tests/test_plotter.py -v`
Expected: PASS (4 passed)

- [ ] **Step 5: Commit**

```bash
git add aimplotter/plotter.py tests/test_plotter.py
git commit -m "feat: GRBL serial plotter driver with soft limits and click"
```

---

### Task 6: Drift corrector

**Files:**
- Create: `aimplotter/drift.py`
- Test: `tests/test_drift.py`

**Interfaces:**
- Produces: `DriftCorrector(bed_center_mm, idle_frames, step_mm)` with:
  - `on_target_frame()` — call when a ball is being aimed at (resets idle counter).
  - `tick(plotter) -> bool` — call on a no-target frame; once idle counter ≥ idle_frames, jog the plotter one `step_mm` toward bed-center. Returns True if it issued a move.
- Consumes: `GRBLPlotter.position` and `.jog()` (Task 5).

- [ ] **Step 1: Write the failing tests**

`tests/test_drift.py`:
```python
from aimplotter.drift import DriftCorrector

class FakeP:
    def __init__(self, pos):
        self._pos = pos
        self.jogs = []

    @property
    def position(self):
        return self._pos

    def jog(self, dx, dy):
        self.jogs.append((dx, dy))
        self._pos = (self._pos[0] + dx, self._pos[1] + dy)
        return True

def test_does_not_move_before_idle_threshold():
    d = DriftCorrector(bed_center_mm=(0.0, 0.0), idle_frames=3, step_mm=1.0)
    p = FakeP((5.0, 0.0))
    assert d.tick(p) is False     # frame 1
    assert d.tick(p) is False     # frame 2
    assert p.jogs == []

def test_moves_toward_center_after_idle():
    d = DriftCorrector(bed_center_mm=(0.0, 0.0), idle_frames=2, step_mm=1.0)
    p = FakeP((5.0, -3.0))
    d.tick(p)                     # 1
    moved = d.tick(p)            # 2 -> threshold reached
    assert moved is True
    dx, dy = p.jogs[-1]
    assert dx < 0 and dy > 0      # toward center from (+5,-3)

def test_on_target_frame_resets_idle():
    d = DriftCorrector(bed_center_mm=(0.0, 0.0), idle_frames=2, step_mm=1.0)
    p = FakeP((5.0, 0.0))
    d.tick(p)
    d.on_target_frame()
    assert d.tick(p) is False     # counter was reset

def test_does_not_overshoot_center():
    d = DriftCorrector(bed_center_mm=(0.0, 0.0), idle_frames=1, step_mm=10.0)
    p = FakeP((3.0, 0.0))
    d.tick(p)
    assert abs(p.position[0]) <= 3.0   # never crosses past center
```

- [ ] **Step 2: Run tests to verify they fail**

Run: `python -m pytest tests/test_drift.py -v`
Expected: FAIL with `ModuleNotFoundError: No module named 'aimplotter.drift'`

- [ ] **Step 3: Write `aimplotter/drift.py`**

```python
class DriftCorrector:
    def __init__(self, bed_center_mm, idle_frames, step_mm):
        self.center = bed_center_mm
        self.idle_frames = idle_frames
        self.step_mm = step_mm
        self._idle = 0

    def on_target_frame(self) -> None:
        self._idle = 0

    def _toward_center(self, pos_axis, center_axis) -> float:
        delta = center_axis - pos_axis
        if abs(delta) <= self.step_mm:
            return delta               # land exactly, no overshoot
        return self.step_mm if delta > 0 else -self.step_mm

    def tick(self, plotter) -> bool:
        self._idle += 1
        if self._idle < self.idle_frames:
            return False
        x, y = plotter.position
        dx = self._toward_center(x, self.center[0])
        dy = self._toward_center(y, self.center[1])
        if dx == 0.0 and dy == 0.0:
            return False
        plotter.jog(dx, dy)
        return True
```

- [ ] **Step 4: Run tests to verify they pass**

Run: `python -m pytest tests/test_drift.py -v`
Expected: PASS (4 passed)

- [ ] **Step 5: Commit**

```bash
git add aimplotter/drift.py tests/test_drift.py
git commit -m "feat: drift corrector reclaims travel during dead time"
```

---

### Task 7: Screen capture

**Files:**
- Create: `aimplotter/capture.py`

**Interfaces:**
- Produces: `ScreenCapture(region)` with `grab() -> numpy.uint8 BGR HxWx3` and `close()`.
- Consumes: `Config.screen_region` (Task 1).

No unit test (thin wrapper over `mss` + OS screen; covered indirectly by the integration test's injected frame source). Verify manually in Step 2.

- [ ] **Step 1: Write `aimplotter/capture.py`**

```python
import numpy as np
import mss

class ScreenCapture:
    def __init__(self, region):
        self.region = region
        self._sct = mss.mss()

    def grab(self):
        shot = self._sct.grab(self.region)
        frame = np.array(shot)              # BGRA
        return frame[:, :, :3]             # drop alpha -> BGR

    def close(self) -> None:
        self._sct.close()
```

- [ ] **Step 2: Manual smoke check**

Run:
```bash
python -c "from aimplotter.capture import ScreenCapture; from aimplotter.config import Config; c=ScreenCapture(Config().screen_region); f=c.grab(); print(f.shape, f.dtype); c.close()"
```
Expected: prints `(1080, 1920, 3) uint8` (or your actual resolution).

- [ ] **Step 3: Commit**

```bash
git add aimplotter/capture.py
git commit -m "feat: mss screen capture"
```

---

### Task 8: Main loop, kill-switch, dry-run, and integration test

**Files:**
- Create: `aimplotter/main.py`
- Test: `tests/test_integration.py`

**Interfaces:**
- Consumes: every module above.
- Produces: `run_loop(frame_source, plotter, controller, drift, config, should_stop)` — one testable function driving the loop; returns a list of action strings (`"jog"`, `"click"`, `"drift"`, `"idle"`) for assertion. `frame_source()` returns a BGR frame or `None` to end. `should_stop()` returns bool (kill-switch).
- Produces: `main(argv)` CLI entry: parses `--no-serial` (dry-run prints G-code), opens serial/capture, installs `pynput` kill-key listener, calls `run_loop`.

- [ ] **Step 1: Write the failing integration test**

`tests/test_integration.py`:
```python
import numpy as np
import cv2
from aimplotter.main import run_loop
from aimplotter.controller import PDController
from aimplotter.drift import DriftCorrector
from aimplotter.config import Config

class FakeP:
    def __init__(self):
        self._pos = (0.0, 0.0)
        self.clicks = 0
        self.jogs = 0

    @property
    def position(self):
        return self._pos

    def jog(self, dx, dy):
        self._pos = (self._pos[0] + dx, self._pos[1] + dy)
        self.jogs += 1
        return True

    def click(self):
        self.clicks += 1

def _frame(cx, cy, r=25):
    f = np.zeros((1080, 1920, 3), dtype=np.uint8)
    if cx is not None:
        cv2.circle(f, (cx, cy), r, (255, 80, 0), -1)
    return f

def test_loop_jogs_then_clicks_then_drifts():
    C = Config()
    # frame 1: ball far from center -> jog; frame 2: ball ON center -> click;
    # frames 3-... : no ball -> drift after idle threshold
    frames = [_frame(1200, 700), _frame(960, 540)]
    frames += [_frame(None, None)] * (C.drift_idle_frames + 1)
    it = iter(frames)

    def source():
        return next(it, None)

    p = FakeP()
    ctrl = PDController(C.gain, C.kp, C.ki, C.kd, C.max_move_mm)
    drift = DriftCorrector(C.bed_center_mm, C.drift_idle_frames, C.drift_step_mm)

    actions = run_loop(source, p, ctrl, drift, C, should_stop=lambda: False)

    assert "jog" in actions
    assert "click" in actions
    assert "drift" in actions
    assert p.clicks >= 1

def test_loop_stops_on_kill_switch():
    C = Config()
    p = FakeP()
    ctrl = PDController(C.gain, C.kp, C.ki, C.kd, C.max_move_mm)
    drift = DriftCorrector(C.bed_center_mm, C.drift_idle_frames, C.drift_step_mm)
    actions = run_loop(lambda: _frame(1200, 700), p, ctrl, drift, C,
                       should_stop=lambda: True)
    assert actions == []
```

- [ ] **Step 2: Run test to verify it fails**

Run: `python -m pytest tests/test_integration.py -v`
Expected: FAIL with `ModuleNotFoundError: No module named 'aimplotter.main'`

- [ ] **Step 3: Write `aimplotter/main.py`**

```python
import argparse
import time

from aimplotter.config import Config
from aimplotter.detector import detect_blue
from aimplotter.targeting import nearest_to_center, error_vector
from aimplotter.controller import PDController, on_target
from aimplotter.drift import DriftCorrector

def run_loop(frame_source, plotter, controller, drift, config,
             should_stop) -> list[str]:
    """Drive one detect->aim->click loop. Returns action log for testing."""
    actions: list[str] = []
    while not should_stop():
        frame = frame_source()
        if frame is None:
            break
        balls = detect_blue(frame, config.hsv_lower, config.hsv_upper,
                            config.min_area_px)
        target = nearest_to_center(balls, config.screen_center)
        if target is None:
            if drift.tick(plotter):
                actions.append("drift")
            else:
                actions.append("idle")
            continue

        drift.on_target_frame()
        err = error_vector(target, config.screen_center)
        if on_target(err, target.r, config.hitbox_tol_px):
            plotter.click()
            controller.reset()
            actions.append("click")
        else:
            dx, dy = controller.step(err)
            plotter.jog(dx, dy)
            actions.append("jog")
    return actions

class _PrintPlotter:
    """Dry-run plotter: prints G-code instead of sending serial."""
    def __init__(self):
        self._pos = (0.0, 0.0)

    @property
    def position(self):
        return self._pos

    def jog(self, dx, dy):
        self._pos = (self._pos[0] + dx, self._pos[1] + dy)
        print(f"[dry-run] $J=G91 X{dx:.3f} Y{dy:.3f}")
        return True

    def click(self):
        print("[dry-run] CLICK")

    def feed_hold(self):
        print("[dry-run] FEED HOLD")

def main(argv=None) -> None:
    parser = argparse.ArgumentParser(description="Optical aim plotter")
    parser.add_argument("--no-serial", action="store_true",
                        help="dry-run: print G-code instead of sending")
    args = parser.parse_args(argv)

    config = Config()
    controller = PDController(config.gain, config.kp, config.ki, config.kd,
                             config.max_move_mm)
    drift = DriftCorrector(config.bed_center_mm, config.drift_idle_frames,
                          config.drift_step_mm)

    # --- kill switch ---
    stop_flag = {"stop": False}
    from pynput import keyboard

    def on_press(key):
        try:
            if key.char == config.kill_key:
                stop_flag["stop"] = True
        except AttributeError:
            pass

    listener = keyboard.Listener(on_press=on_press)
    listener.start()

    # --- capture ---
    from aimplotter.capture import ScreenCapture
    cap = ScreenCapture(config.screen_region)

    # --- plotter ---
    if args.no_serial:
        plotter = _PrintPlotter()
    else:
        import serial
        from aimplotter.plotter import GRBLPlotter
        ser = serial.Serial(config.port, config.baud, timeout=2)
        time.sleep(2)  # let GRBL boot
        plotter = GRBLPlotter(ser, config.soft_limit_mm, config.bed_center_mm,
                             config.press_cmd, config.release_cmd,
                             config.click_dwell_s)

    try:
        run_loop(cap.grab, plotter, controller, drift, config,
                 should_stop=lambda: stop_flag["stop"])
    finally:
        try:
            plotter.feed_hold()
        except Exception:
            pass
        cap.close()
        listener.stop()

if __name__ == "__main__":
    main()
```

- [ ] **Step 4: Run tests to verify they pass**

Run: `python -m pytest tests/test_integration.py -v`
Expected: PASS (2 passed)

- [ ] **Step 5: Run the full suite**

Run: `python -m pytest -v`
Expected: all tests pass (detector, targeting, controller, plotter, drift, integration).

- [ ] **Step 6: Commit**

```bash
git add aimplotter/main.py tests/test_integration.py
git commit -m "feat: main loop, kill-switch, dry-run, integration test"
```

---

### Task 9: Calibration script

**Files:**
- Create: `aimplotter/calibrate.py`

**Interfaces:**
- Consumes: `ScreenCapture`, `GRBLPlotter`, `detect_blue`, `Config`.
- Produces: `measure_gain(capture, plotter, config, move_mm) -> float` — detect a ball, jog the plotter a known `move_mm` in X, re-detect, compute `gain = move_mm / pixels_moved`, print suggested `gain` for `config.py`.

No unit test (hardware + live screen interactive tool). Logic is a thin arithmetic wrapper; verified manually against the printed value.

- [ ] **Step 1: Write `aimplotter/calibrate.py`**

```python
import math
import time

from aimplotter.detector import detect_blue
from aimplotter.targeting import nearest_to_center

def measure_gain(capture, plotter, config, move_mm=5.0) -> float:
    """Jog a known distance, measure view shift in px, return mm-per-px."""
    f0 = capture.grab()
    b0 = nearest_to_center(
        detect_blue(f0, config.hsv_lower, config.hsv_upper, config.min_area_px),
        config.screen_center,
    )
    if b0 is None:
        raise RuntimeError("No ball visible — point at a target before calibrating.")

    plotter.jog(move_mm, 0.0)
    time.sleep(0.3)

    f1 = capture.grab()
    b1 = nearest_to_center(
        detect_blue(f1, config.hsv_lower, config.hsv_upper, config.min_area_px),
        config.screen_center,
    )
    if b1 is None:
        raise RuntimeError("Lost the ball after move — reduce move_mm.")

    px = math.hypot(b1.cx - b0.cx, b1.cy - b0.cy)
    if px < 1:
        raise RuntimeError("No measurable view shift — increase move_mm.")
    gain = move_mm / px
    print(f"Moved {move_mm} mm -> {px:.1f} px shift. "
          f"Suggested config.gain = {gain:.5f}")
    return gain

def main() -> None:
    import time as _t
    import serial
    from aimplotter.config import Config
    from aimplotter.capture import ScreenCapture
    from aimplotter.plotter import GRBLPlotter

    config = Config()
    cap = ScreenCapture(config.screen_region)
    ser = serial.Serial(config.port, config.baud, timeout=2)
    _t.sleep(2)
    plotter = GRBLPlotter(ser, config.soft_limit_mm, config.bed_center_mm,
                         config.press_cmd, config.release_cmd,
                         config.click_dwell_s)
    try:
        measure_gain(cap, plotter, config)
    finally:
        cap.close()

if __name__ == "__main__":
    main()
```

- [ ] **Step 2: Commit**

```bash
git add aimplotter/calibrate.py
git commit -m "feat: interactive gain calibration script"
```

---

## Self-Review

**Spec coverage** (spec §1–§9 → tasks):
- §1 summary / §2 control model → Tasks 4, 8 (PD controller + loop). ✅
- §2 GAIN / calibration → Task 9. ✅
- §3 drift corrector → Task 6. ✅
- §4 components → every module mapped to a task (capture T7, detector T2, targeting T3, controller T4, plotter T5, drift T6, calibrate T9, config T1, main T8). ✅
- §5 safety / kill-switch / dry-run → Task 8 (`should_stop`, `feed_hold` in finally, `--no-serial`, `_PrintPlotter`). ✅
- §6 known constraint (soft limits) → Task 5 (`_clamp`, `jog` returns False). ✅
- §7 testing → tests in Tasks 2–6, 8. ✅
- §8 stack → `requirements.txt` Task 1. ✅
- §9 hardware assumptions / configurable click → Task 1 config + Task 5 `press_cmd`/`release_cmd`. ✅

**Placeholder scan:** No TBD/TODO; every code step shows full code. ✅

**Type consistency:** `Ball(cx,cy,r)`/`.center` consistent across T1–T8; `detect_blue(frame, hsv_lower, hsv_upper, min_area)` signature identical in T2 usage and T8 call; `PDController(gain,kp,ki,kd,max_move_mm)` + `.step()`/`.reset()` consistent T4/T8; `GRBLPlotter` ctor args match T5 def and T8/T9 calls; `DriftCorrector(bed_center_mm,idle_frames,step_mm)` + `.tick()`/`.on_target_frame()` consistent T6/T8; `run_loop(frame_source, plotter, controller, drift, config, should_stop)` consistent T8 def/tests. ✅

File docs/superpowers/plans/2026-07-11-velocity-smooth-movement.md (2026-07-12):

# Velocity-Based Smooth Movement Implementation Plan

> **For agentic workers:** REQUIRED SUB-SKILL: Use superpowers:subagent-driven-development (recommended) or superpowers:executing-plans to implement this plan task-by-task. Steps use checkbox (`- [ ]`) syntax for tracking.

**Goal:** Replace the choppy stop-start aim system with a continuous velocity-streaming system where the controller commands per-axis speed and the firmware runs steppers non-blocking, so motion glides instead of halting every frame.

**Architecture:** New parallel modules alongside the existing ones. A `VelocityController` maps pixel error (plus target-motion feedforward) to per-axis velocity in mm/s. A `VelocityPlotter` streams `V vx vy` commands fire-and-forget. A `velocity_main.run_velocity_loop` drives detect→aim→click with no settle sleep and no per-move ack stall. A new firmware sketch runs the steppers at a continuously slewed commanded speed with a safety watchdog and firmware-authoritative soft limits.

**Tech Stack:** Python 3, OpenCV/numpy (detection, reused), pyserial, pytest; Arduino C++ with AccelStepper + Servo.

## Global Constraints

- Existing files are **left untouched**: `controller.py`, `plotter.py`, `main.py`, `mm6000.ino`, `calibrate.py`, and their tests must still pass.
- All Python source lives under `code/aimplotter/`; all tests under `code/tests/`. Tests are run with the working directory `code/` so `import aimplotter.*` resolves (no pytest config file exists — match existing convention).
- New Python modules import from the existing package: `aimplotter.models.Ball`, `aimplotter.targeting.{error_vector,nearest_to_center}`, `aimplotter.detector.detect_blue`, `aimplotter.controller.on_target`, `aimplotter.tracker.{Tracker,select_locked}`.
- Firmware protocol for velocity: `V <vx_mm_s> <vy_mm_s>\n` is **fire-and-forget (no `ok` ack)**. `S <angle>\n` keeps its `ok` ack. `!` aborts (zeroes target velocity).
- Float wire format: 3 decimals (`f"{v:.3f}"`), matching the existing `J` command format.
- Firmware origin: stepper `currentPosition()` starts at 0 = bed center, matching the Python `bed_center_mm=(0,0)` reference. Soft limit in steps = `soft_limit_mm * STEPS_PER_MM`.
- Watchdog timeout: 200 ms. Firmware constant `WATCHDOG_MS = 200`; config mirror `vel_watchdog_ms = 200`.

---

### Task 1: Config velocity fields

**Files:**
- Modify: `code/aimplotter/config.py` (append fields to the `Config` dataclass)
- Test: `code/tests/test_config_velocity.py` (create)

**Interfaces:**
- Consumes: existing `Config` dataclass.
- Produces: new attributes on `Config`: `kp_v: float`, `kff: float`, `max_speed_mm_s: float`, `vel_watchdog_ms: int`, `vel_deadzone_tol_px: float`. (Reuses existing `gain`, `invert_x`, `invert_y`, `screen_center`, `hitbox_tol_px`, soft-limit/servo/serial fields.)

- [ ] **Step 1: Write the failing test**

Create `code/tests/test_config_velocity.py`:

```python
from aimplotter.config import Config

def test_velocity_defaults_present():
    c = Config()
    assert c.kp_v > 0
    assert c.kff >= 0
    assert c.max_speed_mm_s > 0
    assert c.vel_watchdog_ms == 200
    assert c.vel_deadzone_tol_px > 0

def test_velocity_fields_do_not_disturb_existing():
    c = Config()
    assert c.gain == 0.24          # existing stop-start knob untouched
    assert c.move_settle_s == 0.04
```

- [ ] **Step 2: Run test to verify it fails**

Run: `cd code && python -m pytest tests/test_config_velocity.py -v`
Expected: FAIL — `AttributeError: 'Config' object has no attribute 'kp_v'`

- [ ] **Step 3: Add the fields**

In `code/aimplotter/config.py`, after the `# --- control ---` block (immediately before the `# --- plotter / serial ---` comment), insert:

```python
    # --- velocity control (smooth streaming system) ---
    kp_v: float = 0.05            # mm/s commanded speed per px of error
    kff: float = 0.5             # feedforward scale on target pixel motion
    max_speed_mm_s: float = 40.0  # velocity magnitude clamp
    vel_watchdog_ms: int = 200    # firmware halts if no V within this window
    vel_deadzone_tol_px: float = 6.0  # hold zone = ball radius + this
```

- [ ] **Step 4: Run test to verify it passes**

Run: `cd code && python -m pytest tests/test_config_velocity.py -v`
Expected: PASS (2 passed)

- [ ] **Step 5: Commit**

```bash
git add code/aimplotter/config.py code/tests/test_config_velocity.py
git commit -m "feat: add velocity-control config fields"
```

---

### Task 2: VelocityController

**Files:**
- Create: `code/aimplotter/velocity_controller.py`
- Test: `code/tests/test_velocity_controller.py`

**Interfaces:**
- Consumes: `Config.kp_v`, `Config.kff`, `Config.gain`, `Config.max_speed_mm_s`.
- Produces:
  - `class VelocityController(kp_v: float, kff: float, gain: float, max_speed_mm_s: float)`
  - `VelocityController.reset() -> None`
  - `VelocityController.step(target_px: tuple[float, float], center: tuple[float, float], dt: float) -> tuple[float, float]` — returns `(vx_mm_s, vy_mm_s)`.
  - The returned velocity uses the same sign convention as `error_vector` (target minus center); axis inversion is applied by the caller, not here.

- [ ] **Step 1: Write the failing test**

Create `code/tests/test_velocity_controller.py`:

```python
import math
from aimplotter.velocity_controller import VelocityController

def test_velocity_proportional_to_error():
    c = VelocityController(kp_v=0.05, kff=0.0, gain=0.2, max_speed_mm_s=100.0)
    vx, vy = c.step(target_px=(1060.0, 440.0), center=(960.0, 540.0), dt=0.03)
    # error = (+100, -100); kff=0 so pure P
    assert math.isclose(vx, 5.0, abs_tol=1e-6)   # 100 * 0.05
    assert math.isclose(vy, -5.0, abs_tol=1e-6)  # -100 * 0.05

def test_feedforward_adds_target_motion():
    c = VelocityController(kp_v=0.0, kff=1.0, gain=0.2, max_speed_mm_s=100.0)
    # first sample seeds prev; error term zero (kp_v=0), no prev motion yet
    v0 = c.step(target_px=(960.0, 540.0), center=(960.0, 540.0), dt=0.1)
    assert v0 == (0.0, 0.0)
    # target moved +30px in x over dt=0.1s -> 300 px/s; ff = kff*gain*300 = 60 mm/s
    vx, vy = c.step(target_px=(990.0, 540.0), center=(960.0, 540.0), dt=0.1)
    assert math.isclose(vx, 60.0, abs_tol=1e-6)
    assert math.isclose(vy, 0.0, abs_tol=1e-6)

def test_velocity_is_clamped():
    c = VelocityController(kp_v=1.0, kff=0.0, gain=0.2, max_speed_mm_s=5.0)
    vx, vy = c.step(target_px=(1060.0, 540.0), center=(960.0, 540.0), dt=0.03)
    assert math.isclose(math.hypot(vx, vy), 5.0, abs_tol=1e-6)

def test_reset_clears_feedforward_history():
    c = VelocityController(kp_v=0.0, kff=1.0, gain=0.2, max_speed_mm_s=100.0)
    c.step(target_px=(960.0, 540.0), center=(960.0, 540.0), dt=0.1)
    c.reset()
    # after reset the next sample is treated as first -> no feedforward
    vx, vy = c.step(target_px=(990.0, 540.0), center=(960.0, 540.0), dt=0.1)
    assert vx == 0.0 and vy == 0.0

def test_zero_or_negative_dt_skips_feedforward():
    c = VelocityController(kp_v=0.0, kff=1.0, gain=0.2, max_speed_mm_s=100.0)
    c.step(target_px=(960.0, 540.0), center=(960.0, 540.0), dt=0.1)
    vx, vy = c.step(target_px=(990.0, 540.0), center=(960.0, 540.0), dt=0.0)
    assert vx == 0.0 and vy == 0.0
```

- [ ] **Step 2: Run test to verify it fails**

Run: `cd code && python -m pytest tests/test_velocity_controller.py -v`
Expected: FAIL — `ModuleNotFoundError: No module named 'aimplotter.velocity_controller'`

- [ ] **Step 3: Write the implementation**

Create `code/aimplotter/velocity_controller.py`:

```python
import math

class VelocityController:
    """Maps a target's pixel position to a per-axis velocity command (mm/s).

    v = kp_v * error_px + kff * gain * target_pixel_velocity

    The proportional term chases the error; the feedforward term matches the
    target's own frame-to-frame motion so a moving target is tracked with less
    lag. Output magnitude is clamped to max_speed_mm_s. Sign convention matches
    error_vector (target - center); axis inversion is the caller's job.
    """

    def __init__(self, kp_v, kff, gain, max_speed_mm_s):
        self.kp_v = kp_v
        self.kff = kff
        self.gain = gain            # mm per px, converts px/s -> mm/s
        self.max_speed_mm_s = max_speed_mm_s
        self.reset()

    def reset(self) -> None:
        self._prev_target = None

    def step(self, target_px, center, dt) -> tuple[float, float]:
        ex = target_px[0] - center[0]
        ey = target_px[1] - center[1]

        if self._prev_target is None or dt <= 0:
            tvx = tvy = 0.0
        else:
            tvx = (target_px[0] - self._prev_target[0]) / dt
            tvy = (target_px[1] - self._prev_target[1]) / dt
        self._prev_target = (target_px[0], target_px[1])

        vx = self.kp_v * ex + self.kff * self.gain * tvx
        vy = self.kp_v * ey + self.kff * self.gain * tvy

        mag = math.hypot(vx, vy)
        if mag > self.max_speed_mm_s and mag > 0:
            scale = self.max_speed_mm_s / mag
            vx *= scale
            vy *= scale
        return (vx, vy)
```

- [ ] **Step 4: Run test to verify it passes**

Run: `cd code && python -m pytest tests/test_velocity_controller.py -v`
Expected: PASS (5 passed)

- [ ] **Step 5: Commit**

```bash
git add code/aimplotter/velocity_controller.py code/tests/test_velocity_controller.py
git commit -m "feat: VelocityController maps error + feedforward to mm/s"
```

---

### Task 3: VelocityPlotter

**Files:**
- Create: `code/aimplotter/velocity_plotter.py`
- Test: `code/tests/test_velocity_plotter.py`

**Interfaces:**
- Consumes: a serial-like object with `write(bytes)` and `readline() -> bytes`; `Config` press/release/dwell/servo fields.
- Produces:
  - `class VelocityPlotter(serial_obj, press_angle, release_angle, click_dwell_s, sleep_fn=time.sleep)`
  - `VelocityPlotter.set_velocity(vx_mm_s: float, vy_mm_s: float) -> None` — writes `V vx vy\n`, **never reads** (non-blocking, no ack).
  - `VelocityPlotter.click() -> None` — `S press`, dwell, `S release`; each `S` waits for `ok`.
  - `VelocityPlotter.safe_stop() -> None` — `V 0 0`, `S release`, then `!`.
  - `VelocityPlotter.feed_hold() -> None` — writes `!`.

- [ ] **Step 1: Write the failing test**

Create `code/tests/test_velocity_plotter.py`:

```python
from aimplotter.velocity_plotter import VelocityPlotter

class FakeSerial:
    def __init__(self):
        self.written = []
        self.readline_calls = 0

    def write(self, data):
        self.written.append(data.decode())

    def readline(self):
        self.readline_calls += 1
        return b"ok\n"

def _plotter(ser):
    return VelocityPlotter(ser, press_angle=60, release_angle=90,
                           click_dwell_s=0.0, sleep_fn=lambda s: None)

def test_set_velocity_streams_v_command_without_reading():
    ser = FakeSerial()
    p = _plotter(ser)
    p.set_velocity(1.5, -2.0)
    assert ser.written[-1] == "V 1.500 -2.000\n"
    assert ser.readline_calls == 0        # fire-and-forget, no ack-wait

def test_click_sends_press_then_release_and_acks():
    ser = FakeSerial()
    p = _plotter(ser)
    p.click()
    assert ser.written[-2].strip() == "S 60"
    assert ser.written[-1].strip() == "S 90"
    assert ser.readline_calls >= 2        # each S waits for ok

def test_safe_stop_zeroes_velocity_releases_then_halts():
    ser = FakeSerial()
    p = _plotter(ser)
    p.safe_stop()
    assert ser.written[0] == "V 0.000 0.000\n"
    assert any(w.strip() == "S 90" for w in ser.written)
    assert ser.written[-1] == "!"

def test_feed_hold_sends_bang():
    ser = FakeSerial()
    p = _plotter(ser)
    p.feed_hold()
    assert ser.written[-1] == "!"
```

- [ ] **Step 2: Run test to verify it fails**

Run: `cd code && python -m pytest tests/test_velocity_plotter.py -v`
Expected: FAIL — `ModuleNotFoundError: No module named 'aimplotter.velocity_plotter'`

- [ ] **Step 3: Write the implementation**

Create `code/aimplotter/velocity_plotter.py`:

```python
import time

class VelocityPlotter:
    """Streams continuous velocity setpoints to the velocity firmware.

    Protocol: 'V <vx> <vy>\\n' sets per-axis mm/s and is fire-and-forget (the
    firmware does not ack it, so we never block reading). 'S <angle>\\n' drives
    the click servo and IS acked with 'ok'. '!' is a realtime abort.
    """

    def __init__(self, serial_obj, press_angle, release_angle, click_dwell_s,
                 sleep_fn=time.sleep):
        self.serial = serial_obj
        self.press_angle = press_angle
        self.release_angle = release_angle
        self.click_dwell_s = click_dwell_s
        self._sleep = sleep_fn

    def _send_acked(self, line: str) -> None:
        """Send a command and wait for the firmware 'ok' (used for 'S')."""
        self.serial.write(line.encode())
        for _ in range(100):
            resp = self.serial.readline()
            if not resp:
                break
            text = resp.decode(errors="replace").strip().lower()
            if text.startswith("ok"):
                break
            if text.startswith("err"):
                raise RuntimeError("firmware rejected: " + line.strip())

    def set_velocity(self, vx_mm_s, vy_mm_s) -> None:
        """Stream a velocity setpoint. Non-blocking: writes, never reads."""
        self.serial.write(f"V {vx_mm_s:.3f} {vy_mm_s:.3f}\n".encode())

    def click(self) -> None:
        self._send_acked(f"S {self.press_angle}\n")
        self._sleep(self.click_dwell_s)
        self._send_acked(f"S {self.release_angle}\n")

    def safe_stop(self) -> None:
        """Halt motion, release servo, then realtime abort."""
        self.set_velocity(0.0, 0.0)
        self._send_acked(f"S {self.release_angle}\n")
        self.serial.write(b"!")

    def feed_hold(self) -> None:
        self.serial.write(b"!")  # realtime, no ack
```

- [ ] **Step 4: Run test to verify it passes**

Run: `cd code && python -m pytest tests/test_velocity_plotter.py -v`
Expected: PASS (4 passed)

- [ ] **Step 5: Commit**

```bash
git add code/aimplotter/velocity_plotter.py code/tests/test_velocity_plotter.py
git commit -m "feat: VelocityPlotter streams non-blocking V setpoints"
```

---

### Task 4: velocity_main run loop

**Files:**
- Create: `code/aimplotter/velocity_main.py`
- Test: `code/tests/test_velocity_integration.py`

**Interfaces:**
- Consumes: `VelocityController.step`, `VelocityController.reset`, a plotter with `set_velocity/click/safe_stop`, `detect_blue`, `nearest_to_center`, `error_vector`, `on_target`, `Tracker`/`select_locked` (optional), `Config`.
- Produces:
  - `run_velocity_loop(frame_source, plotter, controller, config, should_stop, clock, tracker=None) -> list[str]` — action log with entries drawn from `{"vel", "hold", "click", "idle"}`.
  - `clock` is a zero-arg callable returning seconds (default `time.monotonic` in `main`); used to compute `dt` between frames for feedforward.
  - `class _PrintVelocityPlotter` — dry-run plotter printing `V`/`CLICK`.
  - `main(argv=None) -> None` — wires capture, kill switch, serial, and the loop.

- [ ] **Step 1: Write the failing test**

Create `code/tests/test_velocity_integration.py`:

```python
import numpy as np
import cv2
from aimplotter.velocity_main import run_velocity_loop
from aimplotter.velocity_controller import VelocityController
from aimplotter.config import Config

class FakeVP:
    def __init__(self):
        self.velocities = []
        self.clicks = 0

    def set_velocity(self, vx, vy):
        self.velocities.append((vx, vy))

    def click(self):
        self.clicks += 1

def _frame(cx, cy, r=25):
    f = np.zeros((1080, 1920, 3), dtype=np.uint8)
    if cx is not None:
        cv2.circle(f, (cx, cy), r, (255, 80, 0), -1)
    return f

def _clock_from(seq):
    it = iter(seq)
    return lambda: next(it)

def test_loop_streams_velocity_then_clicks_then_idles():
    C = Config()
    # frame 1: ball off-center -> vel; frame 2: ball ON center -> click;
    # frame 3: no ball -> idle (velocity zeroed)
    frames = [_frame(1200, 700), _frame(960, 540), _frame(None, None)]
    it = iter(frames)

    def source():
        return next(it, None)

    p = FakeVP()
    ctrl = VelocityController(C.kp_v, C.kff, C.gain, C.max_speed_mm_s)
    clock = _clock_from([0.0, 0.03, 0.06, 0.09])

    actions = run_velocity_loop(source, p, ctrl, C,
                                should_stop=lambda: False, clock=clock)

    assert "vel" in actions
    assert "click" in actions
    assert "idle" in actions
    assert p.clicks >= 1
    assert p.velocities[-1] == (0.0, 0.0)   # idle zeroes velocity

def test_loop_stops_on_kill_switch():
    C = Config()
    p = FakeVP()
    ctrl = VelocityController(C.kp_v, C.kff, C.gain, C.max_speed_mm_s)
    actions = run_velocity_loop(lambda: _frame(1200, 700), p, ctrl, C,
                                should_stop=lambda: True,
                                clock=_clock_from([0.0, 0.03]))
    assert actions == []

def test_offcenter_frame_commands_nonzero_velocity():
    C = Config()
    frames = [_frame(1400, 540), _frame(None, None)]
    it = iter(frames)
    p = FakeVP()
    ctrl = VelocityController(C.kp_v, C.kff, C.gain, C.max_speed_mm_s)
    run_velocity_loop(lambda: next(it, None), p, ctrl, C,
                      should_stop=lambda: False,
                      clock=_clock_from([0.0, 0.03, 0.06]))
    vx, vy = p.velocities[0]
    assert vx != 0.0     # ball right of center -> nonzero x velocity
```

- [ ] **Step 2: Run test to verify it fails**

Run: `cd code && python -m pytest tests/test_velocity_integration.py -v`
Expected: FAIL — `ModuleNotFoundError: No module named 'aimplotter.velocity_main'`

- [ ] **Step 3: Write the implementation**

Create `code/aimplotter/velocity_main.py`:

```python
import argparse
import time

from aimplotter.config import Config
from aimplotter.detector import detect_blue
from aimplotter.targeting import nearest_to_center, error_vector
from aimplotter.controller import on_target
from aimplotter.velocity_controller import VelocityController
from aimplotter.tracker import select_locked

def run_velocity_loop(frame_source, plotter, controller, config,
                      should_stop, clock, tracker=None) -> list[str]:
    """Stream velocity setpoints in a detect->aim->click loop.

    No settle sleep and no per-move ack stall: every frame updates the
    velocity setpoint and the firmware keeps the steppers gliding. Returns an
    action log for testing.
    """
    actions: list[str] = []
    locked_id = None
    armed = True                 # may we click? False = already hit, hold still
    prev_t = clock()
    while not should_stop():
        frame = frame_source()
        if frame is None:
            break
        now = clock()
        dt = now - prev_t
        prev_t = now

        balls = detect_blue(frame, config.hsv_lower, config.hsv_upper,
                            config.min_area_px)
        if tracker is not None:
            tracks = tracker.update(balls)
            sel = select_locked(tracks, config.screen_center, locked_id)
            target = sel.ball if sel else None
            locked_id = sel.id if sel else None
        else:
            target = nearest_to_center(balls, config.screen_center)

        if target is None:
            plotter.set_velocity(0.0, 0.0)
            controller.reset()          # drop stale feedforward history
            actions.append("idle")
            continue

        err = error_vector(target, config.screen_center)
        if on_target(err, target.r, config.vel_deadzone_tol_px):
            plotter.set_velocity(0.0, 0.0)
            if armed:
                plotter.click()
                controller.reset()
                armed = False
                actions.append("click")
            else:
                actions.append("hold")
        else:
            armed = True                # crosshair left target -> re-arm
            vx, vy = controller.step(target.center, config.screen_center, dt)
            if config.invert_x:
                vx = -vx
            if config.invert_y:
                vy = -vy
            if config.debug:
                print(f"err=({err[0]:+.0f},{err[1]:+.0f}) "
                      f"vel=({vx:+.2f},{vy:+.2f}) r={target.r:.0f}")
            plotter.set_velocity(vx, vy)
            actions.append("vel")
    return actions

class _PrintVelocityPlotter:
    """Dry-run plotter: prints velocity commands instead of sending serial."""
    def set_velocity(self, vx, vy):
        print(f"[dry-run] V {vx:.3f} {vy:.3f}")

    def click(self):
        print("[dry-run] CLICK")

    def safe_stop(self):
        print("[dry-run] SAFE STOP")

    def feed_hold(self):
        print("[dry-run] FEED HOLD")

def main(argv=None) -> None:
    parser = argparse.ArgumentParser(description="Optical aim plotter (velocity)")
    parser.add_argument("--no-serial", action="store_true",
                        help="dry-run: print velocity commands instead of sending")
    args = parser.parse_args(argv)

    config = Config()
    controller = VelocityController(config.kp_v, config.kff, config.gain,
                                    config.max_speed_mm_s)
    from aimplotter.tracker import Tracker
    tracker = Tracker(config.track_match_dist_px, config.track_max_misses)

    stop_flag = {"stop": False}
    from pynput import keyboard

    def on_press(key):
        try:
            if key.char == config.kill_key:
                stop_flag["stop"] = True
        except AttributeError:
            pass

    listener = keyboard.Listener(on_press=on_press)
    listener.start()

    from aimplotter.capture import make_capture
    cap = make_capture(config)

    if args.no_serial:
        plotter = _PrintVelocityPlotter()
    else:
        import serial
        from aimplotter.velocity_plotter import VelocityPlotter
        ser = serial.Serial(config.port, config.baud, timeout=2)
        time.sleep(2)              # let the Uno finish resetting
        ser.reset_input_buffer()
        plotter = VelocityPlotter(ser, config.press_angle, config.release_angle,
                                  config.click_dwell_s)

    try:
        run_velocity_loop(cap.grab, plotter, controller, config,
                          should_stop=lambda: stop_flag["stop"],
                          clock=time.monotonic, tracker=tracker)
    finally:
        try:
            plotter.safe_stop()
        except Exception:
            pass
        cap.close()
        listener.stop()

if __name__ == "__main__":
    main()
```

- [ ] **Step 4: Run test to verify it passes**

Run: `cd code && python -m pytest tests/test_velocity_integration.py -v`
Expected: PASS (3 passed)

- [ ] **Step 5: Run the full suite to confirm nothing regressed**

Run: `cd code && python -m pytest -v`
Expected: PASS (all existing tests + the new ones)

- [ ] **Step 6: Commit**

```bash
git add code/aimplotter/velocity_main.py code/tests/test_velocity_integration.py
git commit -m "feat: velocity_main streams setpoints with no settle stall"
```

---

### Task 5: Velocity firmware sketch

**Files:**
- Create: `code/firmware/mm6000_velocity/mm6000_velocity.ino`

**Interfaces:**
- Consumes: serial lines `V <vx_mm_s> <vy_mm_s>\n` (no ack), `S <angle>\n` (ack `ok`), `!` (abort). Must match `VelocityPlotter` exactly.
- Produces: continuous non-blocking stepper motion at a slewed commanded speed, watchdog halt, per-axis firmware soft limits.

> **Note:** This task is bench/hardware-tested, not unit-tested (no automated harness for Arduino here). Its deliverable is the sketch plus the manual verification checklist in Step 3. If `arduino-cli` is installed, Step 2 compiles it; otherwise skip Step 2 and rely on the IDE compile + bench test.

- [ ] **Step 1: Write the sketch**

Create `code/firmware/mm6000_velocity/mm6000_velocity.ino`:

```cpp
#include <AccelStepper.h>
#include <Servo.h>
#include <stdlib.h>   // strtod, atoi (avr-libc float sscanf is unsupported)

// --- CNC Shield V3 pin map (A4988 drivers) ---
#define X_STEP 2
#define X_DIR  5
#define Y_STEP 3
#define Y_DIR  6
#define ENABLE 8      // active LOW: energizes all drivers
#define SERVO_PIN 11

// --- machine constants (match mm6000.ino) ---
#define STEPS_PER_MM_X 5.0
#define STEPS_PER_MM_Y 5.0
#define ACCEL 2000.0            // steps/s^2: bounds how fast commanded speed slews
#define MAX_STEP_SPEED 4000.0   // steps/s hard cap per axis

// --- safety ---
#define WATCHDOG_MS 200         // no V within this -> ramp to zero
#define SOFT_LIMIT_MM 90.0      // +/- travel from startup origin
const long LIMIT_STEPS_X = (long)(SOFT_LIMIT_MM * STEPS_PER_MM_X);
const long LIMIT_STEPS_Y = (long)(SOFT_LIMIT_MM * STEPS_PER_MM_Y);

AccelStepper xAxis(AccelStepper::DRIVER, X_STEP, X_DIR);
AccelStepper yAxis(AccelStepper::DRIVER, Y_STEP, Y_DIR);
Servo clickServo;

char buf[48];
uint8_t len = 0;

float targetSpeedX = 0, targetSpeedY = 0;   // steps/s setpoint from last V
float currentSpeedX = 0, currentSpeedY = 0; // slewed actual command
unsigned long lastCmdMillis = 0;
unsigned long lastMicros = 0;

void setup() {
  pinMode(ENABLE, OUTPUT);
  digitalWrite(ENABLE, LOW);   // enable drivers
  xAxis.setMaxSpeed(MAX_STEP_SPEED);
  yAxis.setMaxSpeed(MAX_STEP_SPEED);
  xAxis.setCurrentPosition(0); // origin = bed center reference
  yAxis.setCurrentPosition(0);
  clickServo.attach(SERVO_PIN);
  clickServo.write(90);        // rest angle
  Serial.begin(115200);
  lastMicros = micros();
  lastCmdMillis = millis();
  Serial.println("mm6000v ready");
}

float clampSpeed(float s) {
  if (s > MAX_STEP_SPEED) return MAX_STEP_SPEED;
  if (s < -MAX_STEP_SPEED) return -MAX_STEP_SPEED;
  return s;
}

// Move currentSpeed toward targetSpeed, limited to maxDelta steps/s this tick.
float slew(float current, float target, float maxDelta) {
  if (target > current) {
    current += maxDelta;
    if (current > target) current = target;
  } else if (target < current) {
    current -= maxDelta;
    if (current < target) current = target;
  }
  return current;
}

void handleVelocity(char *args) {
  char *p = args;
  float vx = strtod(p, &p);
  float vy = strtod(p, &p);
  targetSpeedX = clampSpeed(vx * STEPS_PER_MM_X);
  targetSpeedY = clampSpeed(vy * STEPS_PER_MM_Y);
  lastCmdMillis = millis();
  // no ack: this is the streaming hot path
}

void handleServo(char *args) {
  int angle = atoi(args);
  if (angle < 0) angle = 0;
  if (angle > 180) angle = 180;
  clickServo.write(angle);
  Serial.println("ok");
}

void handleLine(char *line) {
  if (line[0] == 'V') {
    handleVelocity(line + 1);
  } else if (line[0] == 'S') {
    handleServo(line + 1);
  } else {
    Serial.println("err");
  }
}

void readSerial() {
  while (Serial.available()) {
    char c = Serial.read();
    if (c == '!') {              // realtime abort: stop commanding motion
      targetSpeedX = 0;
      targetSpeedY = 0;
      len = 0;                   // discard any partial line
      continue;
    }
    if (c == '\n') {
      buf[len] = '\0';
      if (len > 0) handleLine(buf);
      len = 0;
    } else if (len < sizeof(buf) - 1) {
      buf[len++] = c;
    }
  }
}

void loop() {
  readSerial();

  // watchdog: host went quiet -> command zero (slew still ramps it down)
  if (millis() - lastCmdMillis > WATCHDOG_MS) {
    targetSpeedX = 0;
    targetSpeedY = 0;
  }

  unsigned long now = micros();
  float dt = (now - lastMicros) / 1000000.0;
  lastMicros = now;
  if (dt <= 0) dt = 0.0001;
  float maxDelta = ACCEL * dt;   // steps/s of speed change allowed this tick

  currentSpeedX = slew(currentSpeedX, targetSpeedX, maxDelta);
  currentSpeedY = slew(currentSpeedY, targetSpeedY, maxDelta);

  // firmware-authoritative soft limits: if at edge and pushing further, stop axis
  long px = xAxis.currentPosition();
  if ((px <= -LIMIT_STEPS_X && currentSpeedX < 0) ||
      (px >=  LIMIT_STEPS_X && currentSpeedX > 0)) {
    currentSpeedX = 0;
  }
  long py = yAxis.currentPosition();
  if ((py <= -LIMIT_STEPS_Y && currentSpeedY < 0) ||
      (py >=  LIMIT_STEPS_Y && currentSpeedY > 0)) {
    currentSpeedY = 0;
  }

  xAxis.setSpeed(currentSpeedX);
  yAxis.setSpeed(currentSpeedY);
  xAxis.runSpeed();              // non-blocking: one step if due
  yAxis.runSpeed();
}
```

- [ ] **Step 2: Compile (if arduino-cli available)**

Run: `arduino-cli compile --fqbn arduino:avr:uno code/firmware/mm6000_velocity`
Expected: compiles clean. (If `arduino-cli` is not installed, compile in the Arduino IDE instead; this is a manual gate.)

- [ ] **Step 3: Bench-test checklist (manual, hardware)**

Verify on the rig:
- Sending `V 5 0\n` starts smooth continuous X motion; `V 0 0\n` ramps it to a stop (no abrupt halt).
- A setpoint jump (`V 5 0` then `V -5 0`) reverses smoothly through zero, not instantly (slew/ACCEL working).
- Stop streaming for >200 ms → motion ramps to zero on its own (watchdog).
- Drive an axis to the ± soft limit → that axis stops, the other still responds.
- `S 60\n` then `S 90\n` clicks and returns `ok`; `!` halts immediately.

- [ ] **Step 4: Commit**

```bash
git add code/firmware/mm6000_velocity/mm6000_velocity.ino
git commit -m "feat: velocity firmware with slew, watchdog, soft limits"
```

---

## Self-Review Notes

- **Spec coverage:** Firmware V/S/! + slew + watchdog + limits → Task 5. VelocityController P+feedforward+deadzone(caller)+clamp+reset → Task 2. VelocityPlotter set_velocity/click/safe_stop/feed_hold → Task 3. velocity_main loop, no settle/no block, click arming, dry-run → Task 4. Config fields → Task 1. Testing strategy → Tasks 2–4 unit/integration, Task 5 bench.
- **Deadzone location:** the spec allows the deadzone in the controller; this plan places it in the loop via the existing `on_target(err, radius, tol)` (reuse, DRY) with `vel_deadzone_tol_px`. Controller stays pure velocity math. Consistent across all tasks.
- **Type consistency:** `set_velocity(vx, vy)`, `controller.step(target_px, center, dt)`, `run_velocity_loop(..., clock, tracker=None)` used identically in impl and tests.
- **Left intact:** no existing file is modified except `config.py` (additive fields only).
```

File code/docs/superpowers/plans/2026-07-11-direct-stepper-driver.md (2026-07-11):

# Direct Stepper Driver Implementation Plan

> **For agentic workers:** REQUIRED SUB-SKILL: Use superpowers:subagent-driven-development (recommended) or superpowers:executing-plans to implement this plan task-by-task. Steps use checkbox (`- [ ]`) syntax for tracking.

**Goal:** Replace GRBL with custom Arduino firmware that drives the CNC Shield V3's A4988 STEP/DIR pins and click servo directly, controlled from Python over a simple line-based serial protocol.

**Architecture:** The Python↔hardware seam keeps its current shape — send an ASCII line, wait for `ok`. Only the plotter driver internals, a few `config.py` fields, and the (new) Arduino firmware change. Detection, targeting, PD controller, drift corrector, capture, and kill-switch are untouched.

**Tech Stack:** Python 3.10+ · `pyserial` · `pytest` (existing). Arduino C++ · `AccelStepper` · `Servo`.

## Global Constraints

- Python 3.10+ (existing codebase uses `X | None` typing).
- Serial link: USB @ **115200** baud, `\n`-terminated ASCII lines, every command acked `ok\n` (unknown → `err\n`); `!` is a single realtime byte with no newline and no ack.
- Moves are **relative** in millimetres; `steps/mm` lives in firmware `#define`s, not Python.
- No endstops/homing — the Python soft-limit `_clamp` is the sole travel guard.
- Plotter driver public surface is unchanged from `GRBLPlotter`: `jog(dx,dy)->bool`, `click()`, `feed_hold()`, `safe_stop()`, `position` property. Only the class name (`StepperPlotter`) and the bytes it emits change.
- CNC Shield V3 pin map: X.STEP=D2 X.DIR=D5, Y.STEP=D3 Y.DIR=D6, driver ENABLE=D8 (active low), servo=D11.

---

### Task 1: Config — servo angles replace M-code strings

**Files:**
- Modify: `aimplotter/config.py:29-30` (remove `press_cmd`/`release_cmd`)
- Test: covered by Task 3's plotter tests (config has no dedicated test file; the existing `test_targeting.py` config assertions don't touch these fields).

**Interfaces:**
- Produces: `Config.press_angle: int = 60`, `Config.release_angle: int = 90`. Removes `Config.press_cmd`, `Config.release_cmd`.

- [ ] **Step 1: Edit `aimplotter/config.py`**

Replace the two lines in the `--- plotter / serial ---` block:

```python
    press_cmd: str = "M3 S1000"
    release_cmd: str = "M5"
```

with:

```python
    press_angle: int = 60         # servo degrees when clicking
    release_angle: int = 90       # servo degrees at rest
```

Leave `port`, `baud`, `click_dwell_s`, and every other field unchanged.

- [ ] **Step 2: Verify nothing else imports the old fields**

Run: `grep -rn "press_cmd\|release_cmd" aimplotter tests`
Expected: only hits are in `plotter.py`, `main.py`, `calibrate.py`, `tests/test_plotter.py` — all rewritten in Tasks 3–5. No stray references elsewhere.

- [ ] **Step 3: Commit**

```bash
git add aimplotter/config.py
git commit -m "feat: config servo angles replace GRBL M-code strings"
```

---

### Task 2: Arduino firmware — direct stepper + servo driver

**Files:**
- Create: `firmware/mm6000/mm6000.ino`

**Interfaces:**
- Produces: a serial device speaking the protocol in Global Constraints:
  - `J <dx_mm> <dy_mm> <feed_mm_min>\n` → move, then `ok\n`
  - `S <angle>\n` → `servo.write(angle)`, then `ok\n`
  - `!` (one byte) → abort motion, no reply
  - unknown line → `err\n`
- Consumes: nothing from other tasks. `STEPS_PER_MM_X/Y` are measured on hardware and baked in (placeholder `80.0` until calibrated).

No automated test — verified manually on hardware in Step 3. This is a single self-contained deliverable (firmware sketch); it carries its own manual verification, so it is one task.

- [ ] **Step 1: Write `firmware/mm6000/mm6000.ino`**

```cpp
#include <AccelStepper.h>
#include <Servo.h>

// --- CNC Shield V3 pin map (A4988 drivers) ---
#define X_STEP 2
#define X_DIR  5
#define Y_STEP 3
#define Y_DIR  6
#define ENABLE 8      // active LOW: energizes all drivers
#define SERVO_PIN 11

// --- machine constants (measure steps/mm on the built rig, then set) ---
#define STEPS_PER_MM_X 80.0
#define STEPS_PER_MM_Y 80.0
#define ACCEL 2000.0            // steps/s^2
#define DEFAULT_SPEED 1000.0    // steps/s fallback if feed missing/zero

AccelStepper xAxis(AccelStepper::DRIVER, X_STEP, X_DIR);
AccelStepper yAxis(AccelStepper::DRIVER, Y_STEP, Y_DIR);
Servo clickServo;

char buf[48];
uint8_t len = 0;

void setup() {
  pinMode(ENABLE, OUTPUT);
  digitalWrite(ENABLE, LOW);   // enable drivers
  xAxis.setAcceleration(ACCEL);
  yAxis.setAcceleration(ACCEL);
  xAxis.setMaxSpeed(DEFAULT_SPEED);
  yAxis.setMaxSpeed(DEFAULT_SPEED);
  clickServo.attach(SERVO_PIN);
  clickServo.write(90);        // rest angle
  Serial.begin(115200);
  Serial.println("mm6000 ready");
}

// Run both axes to their targets. Returns early if a '!' arrives mid-move.
void runMove() {
  while (xAxis.distanceToGo() != 0 || yAxis.distanceToGo() != 0) {
    if (Serial.available() && Serial.peek() == '!') {
      Serial.read();           // consume the '!'
      xAxis.stop();
      yAxis.stop();
      xAxis.setCurrentPosition(xAxis.currentPosition());
      yAxis.setCurrentPosition(yAxis.currentPosition());
      return;
    }
    xAxis.run();
    yAxis.run();
  }
}

void handleJog(char *args) {
  float dx = 0, dy = 0, feed = 0;
  // args: "<dx_mm> <dy_mm> <feed_mm_min>"
  sscanf(args, "%f %f %f", &dx, &dy, &feed);
  float sx = feed > 0 ? (feed / 60.0) * STEPS_PER_MM_X : DEFAULT_SPEED;
  float sy = feed > 0 ? (feed / 60.0) * STEPS_PER_MM_Y : DEFAULT_SPEED;
  xAxis.setMaxSpeed(sx);
  yAxis.setMaxSpeed(sy);
  xAxis.move((long)lround(dx * STEPS_PER_MM_X));
  yAxis.move((long)lround(dy * STEPS_PER_MM_Y));
  runMove();
  Serial.println("ok");
}

void handleServo(char *args) {
  int angle = 90;
  sscanf(args, "%d", &angle);
  if (angle < 0) angle = 0;
  if (angle > 180) angle = 180;
  clickServo.write(angle);
  Serial.println("ok");
}

void handleLine(char *line) {
  if (line[0] == 'J') {
    handleJog(line + 1);
  } else if (line[0] == 'S') {
    handleServo(line + 1);
  } else {
    Serial.println("err");
  }
}

void loop() {
  while (Serial.available()) {
    char c = Serial.read();
    if (c == '!') {            // realtime abort when idle: nothing to stop
      xAxis.stop();
      yAxis.stop();
      len = 0;                 // discard any partial line
      continue;
    }
    if (c == '\n') {
      buf[len] = '\0';
      if (len > 0) handleLine(buf);
      len = 0;
    } else if (len < sizeof(buf) - 1) {
      buf[len++] = c;
    }
  }
}
```

- [ ] **Step 2: Compile-check**

Install `AccelStepper` via Arduino Library Manager, then verify the sketch compiles:

Run (Arduino CLI): `arduino-cli compile --fqbn arduino:avr:uno firmware/mm6000`
Expected: `Sketch uses ... bytes`, no errors. (Or use the IDE's Verify button.)

- [ ] **Step 3: Manual hardware smoke test**

Flash to the Uno. Open Serial Monitor @ 115200, line ending = Newline.
- Expect banner `mm6000 ready`.
- Send `J 10 0 3000` → X carriage moves ~10 mm, replies `ok`. (Exact mm depends on `STEPS_PER_MM_X`; correct the `#define` once measured.)
- Send `S 60` → servo presses, `ok`. Send `S 90` → releases, `ok`.
- Send `J 50 0 3000` then, mid-move, `!` → motion stops immediately.

- [ ] **Step 4: Commit**

```bash
git add firmware/mm6000/mm6000.ino
git commit -m "feat: Arduino direct stepper+servo firmware, serial protocol"
```

---

### Task 3: StepperPlotter driver + tests

**Files:**
- Modify: `aimplotter/plotter.py` (rename class, replace protocol)
- Test: `tests/test_plotter.py` (rewrite assertions)

**Interfaces:**
- Consumes: `Config.press_angle`, `Config.release_angle` (Task 1); the firmware protocol (Task 2).
- Produces: `StepperPlotter(serial_obj, soft_limit_mm, bed_center_mm, press_angle, release_angle, click_dwell_s, feed_mm_min=3000, sleep_fn=time.sleep)` with `jog(dx_mm, dy_mm) -> bool`, `click() -> None`, `feed_hold() -> None`, `safe_stop() -> None`, `position -> tuple[float, float]`.

- [ ] **Step 1: Rewrite the failing tests in `tests/test_plotter.py`**

Replace the whole file with:

```python
from aimplotter.plotter import StepperPlotter

class FakeSerial:
    def __init__(self):
        self.written = []
        self._lines = []

    def write(self, data):
        self.written.append(data.decode())
        self._lines.append(b"ok\n")  # firmware acks every line

    def readline(self):
        return self._lines.pop(0) if self._lines else b"ok\n"

def _plotter():
    return StepperPlotter(
        FakeSerial(), soft_limit_mm=10.0, bed_center_mm=(0.0, 0.0),
        press_angle=60, release_angle=90, click_dwell_s=0.0,
        sleep_fn=lambda s: None,
    )

def test_jog_sends_relative_move_and_tracks_position():
    p = _plotter()
    ok = p.jog(2.0, -1.5)
    assert ok is True
    assert p.position == (2.0, -1.5)
    sent = p.serial.written[-1]
    assert sent.startswith("J ")
    parts = sent.strip().split()
    assert parts[1] == "2.000" and parts[2] == "-1.500"
    assert parts[3] == "3000"          # default feed

def test_jog_clamps_to_soft_limits():
    p = _plotter()
    ok = p.jog(50.0, 0.0)              # beyond +10 limit
    assert ok is False
    assert p.position[0] == 10.0       # clamped to limit

def test_click_sends_press_then_release_angles():
    p = _plotter()
    p.click()
    assert p.serial.written[-2].strip() == "S 60"
    assert p.serial.written[-1].strip() == "S 90"

def test_feed_hold_sends_bang():
    p = _plotter()
    p.feed_hold()
    assert p.serial.written[-1] == "!"

def test_safe_stop_releases_then_halts():
    p = _plotter()
    p.safe_stop()
    assert any(w.strip() == "S 90" for w in p.serial.written)
    assert p.serial.written[-1] == "!"
```

- [ ] **Step 2: Run tests to verify they fail**

Run: `python -m pytest tests/test_plotter.py -v`
Expected: FAIL with `ImportError: cannot import name 'StepperPlotter'`.

- [ ] **Step 3: Rewrite `aimplotter/plotter.py`**

Replace the whole file with:

```python
import time

class StepperPlotter:
    """Drives the custom Arduino firmware over serial.

    Protocol: 'J <dx> <dy> <feed>\\n' relative move, 'S <angle>\\n' servo,
    '!' realtime abort. Every non-'!' command is acked 'ok'.
    """

    def __init__(self, serial_obj, soft_limit_mm, bed_center_mm,
                 press_angle, release_angle, click_dwell_s,
                 feed_mm_min=3000, sleep_fn=time.sleep):
        self.serial = serial_obj
        self.soft_limit_mm = soft_limit_mm
        self.center = bed_center_mm
        self.press_angle = press_angle
        self.release_angle = release_angle
        self.click_dwell_s = click_dwell_s
        self.feed_mm_min = feed_mm_min
        self._sleep = sleep_fn
        self._x, self._y = bed_center_mm

    @property
    def position(self) -> tuple[float, float]:
        return (self._x, self._y)

    def _send(self, line: str) -> None:
        """Send a command, wait for 'ok'."""
        self.serial.write(line.encode())
        for _ in range(100):
            resp = self.serial.readline()
            if not resp:
                break
            text = resp.decode(errors="replace").strip().lower()
            if text.startswith("ok"):
                break
            if text.startswith("err"):
                raise RuntimeError("firmware rejected: " + line.strip())

    def _clamp(self, target, axis_center):
        lo = axis_center - self.soft_limit_mm
        hi = axis_center + self.soft_limit_mm
        if target < lo:
            return lo, True
        if target > hi:
            return hi, True
        return target, False

    def jog(self, dx_mm, dy_mm) -> bool:
        nx, cx_clamped = self._clamp(self._x + dx_mm, self.center[0])
        ny, cy_clamped = self._clamp(self._y + dy_mm, self.center[1])
        real_dx = nx - self._x
        real_dy = ny - self._y
        line = f"J {real_dx:.3f} {real_dy:.3f} {self.feed_mm_min}\n"
        self._send(line)
        self._x, self._y = nx, ny
        return not (cx_clamped or cy_clamped)

    def click(self) -> None:
        self._send(f"S {self.press_angle}\n")
        self._sleep(self.click_dwell_s)
        self._send(f"S {self.release_angle}\n")

    def safe_stop(self) -> None:
        """Release servo then abort motion."""
        self._send(f"S {self.release_angle}\n")
        self.serial.write(b"!")

    def feed_hold(self) -> None:
        self.serial.write(b"!")  # realtime, no ack
```

- [ ] **Step 4: Run tests to verify they pass**

Run: `python -m pytest tests/test_plotter.py -v`
Expected: PASS (5 passed).

- [ ] **Step 5: Commit**

```bash
git add aimplotter/plotter.py tests/test_plotter.py
git commit -m "feat: StepperPlotter driver for custom firmware protocol"
```

---
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

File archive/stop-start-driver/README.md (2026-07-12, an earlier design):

# Archived: stop-start driver (reference only)

The original **position-based, move-and-settle** aim driver. Superseded by the
velocity-streaming system in `code/` (`aimplotter/velocity_*.py` +
`firmware/mm6000_velocity/`). Kept here for reference; **not** on the active
import path and not exercised by the test suite.

## What's here
- `firmware/mm6000/mm6000.ino` — Arduino firmware, blocking `J <dx> <dy> <feed>`
  jog protocol (accel/decel to a stop every move) + `S <angle>` servo + `!` abort.
- `plotter.py` — `StepperPlotter`, sends `J`/`S` and waits for `ok` each move.
- `main.py` — `run_loop`: detect → PD position step → jog → settle → repeat.
- `calibrate.py` — measures `gain` (mm/px) by jogging a known distance.
- `tests/` — the tests that covered the above.
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

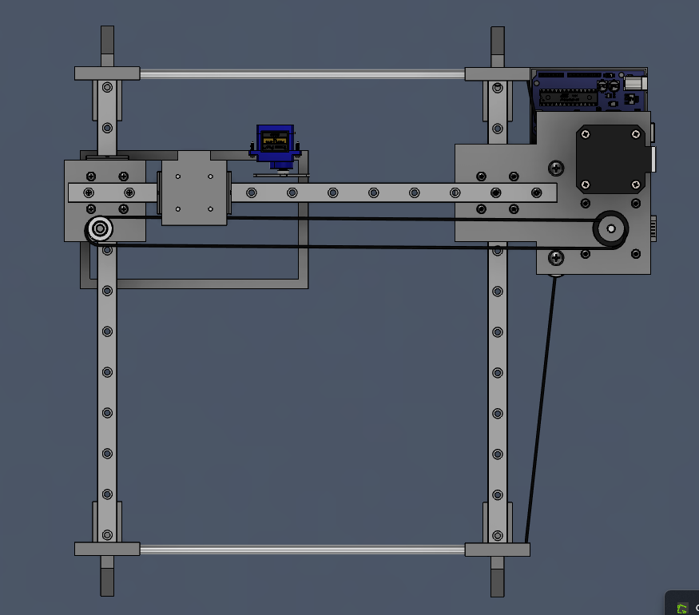
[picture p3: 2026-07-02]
images/mm6 image 4.png

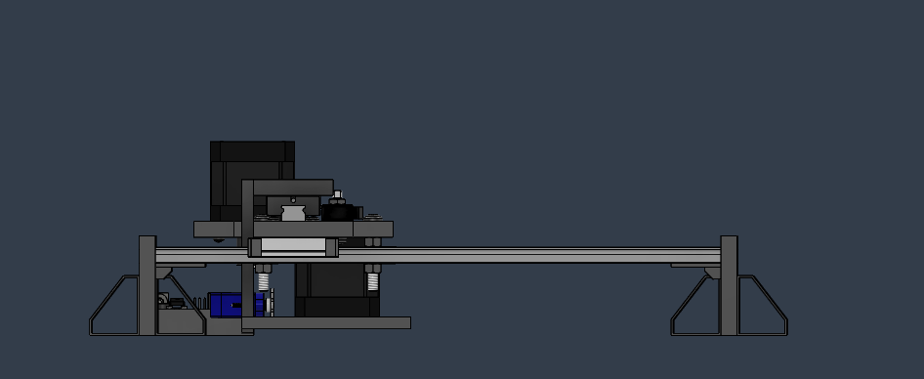
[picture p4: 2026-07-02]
images/mm6 image 3.png

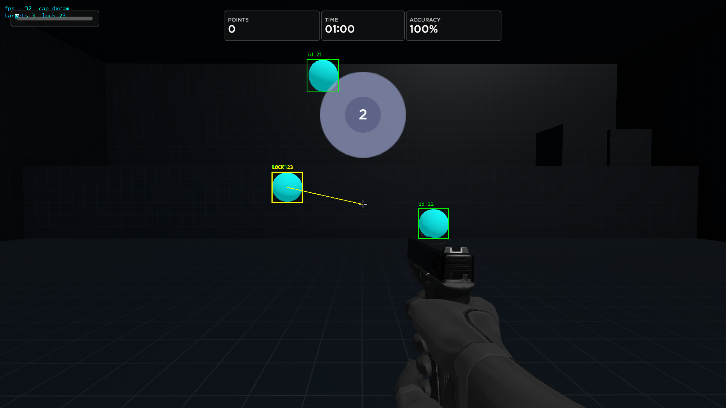
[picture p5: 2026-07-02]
images/mm6 detection code.png

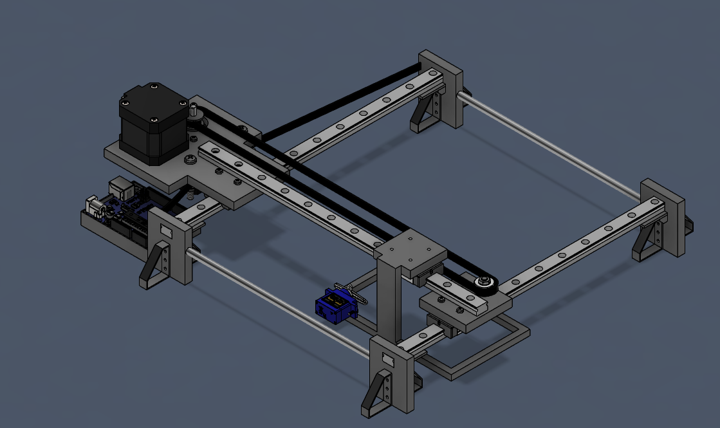
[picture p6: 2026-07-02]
images/mm6 image 1.png

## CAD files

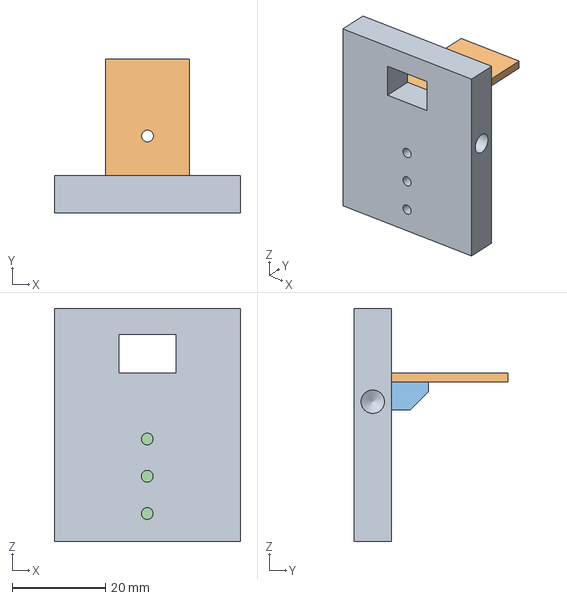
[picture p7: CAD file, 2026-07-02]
CAD/STEP/XY Plotter Left Edge.step
40.0 x 33.0 x 50.0 mm

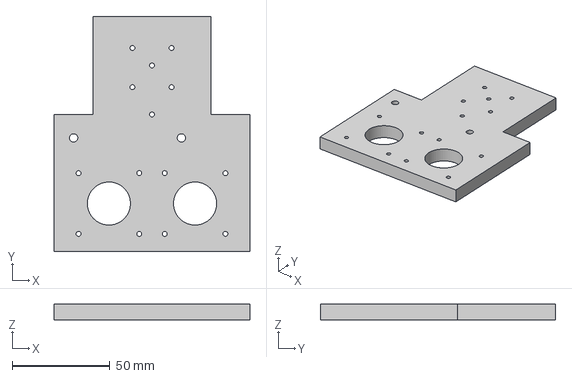
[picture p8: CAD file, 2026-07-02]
CAD/STEP/XY Plotter Central Plate.step
100.0 x 120.0 x 8.00 mm

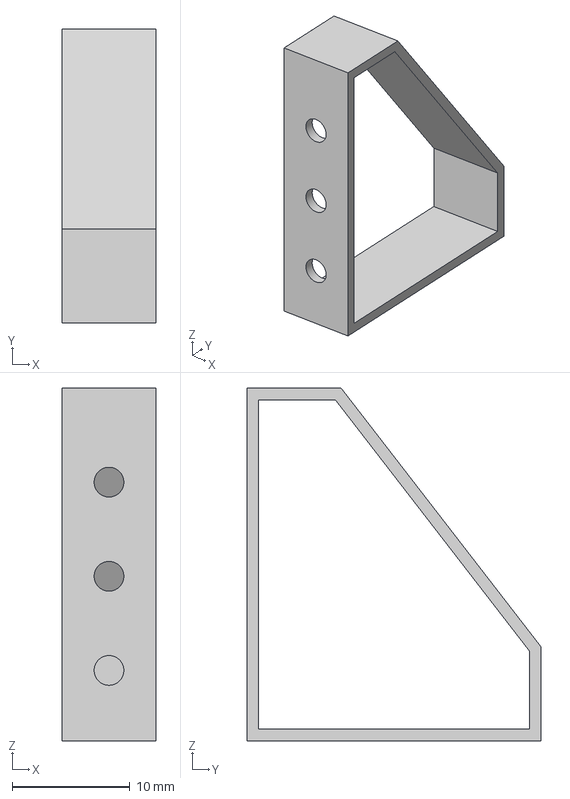
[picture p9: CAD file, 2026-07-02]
CAD/STEP/Triangle Bracket.step
8.00 x 25.0 x 30.0 mm

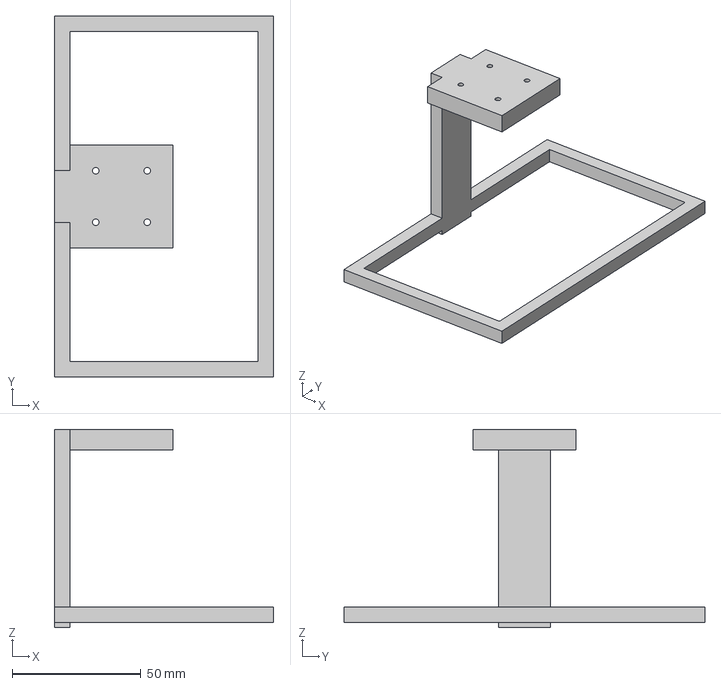
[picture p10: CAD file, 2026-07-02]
CAD/STEP/Y Axis Mount.step
85.0 x 140.0 x 77.0 mm

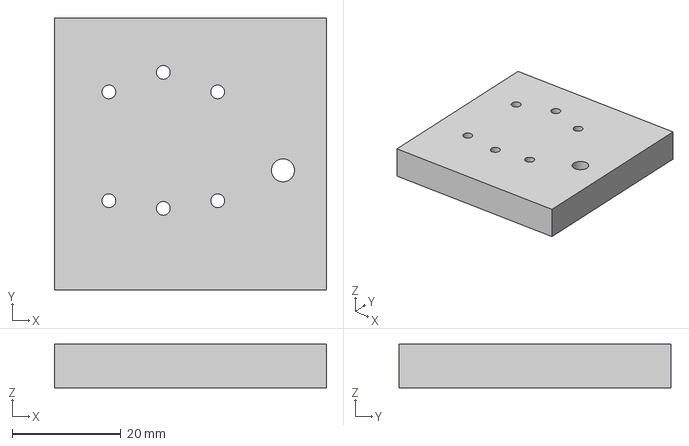
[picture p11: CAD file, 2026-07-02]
CAD/STEP/Y Axis End.step
50.0 x 50.0 x 8.00 mm

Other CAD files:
CAD/STEP/XY Plotter Right Edge.step
CAD/F3D/Triangle Bracket.f3d
CAD/F3D/XY Plotter Central Plate.f3d
CAD/F3D/XY Plotter Left Edge.f3d
CAD/F3D/XY Plotter Right Edge.f3d
CAD/F3D/Y Axis End.f3d
CAD/F3D/Y Axis Mount.f3d

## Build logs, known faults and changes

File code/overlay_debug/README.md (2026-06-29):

# overlay_debug (THROWAWAY DEV TOOL)

> ⚠️ **Delete this entire folder before final deployment.** It is a debugging
> visualization only. It imports from `aimplotter/` (read-only) and modifies
> **no** main files, so removing this folder leaves the project intact.

## What it shows

A transparent, always-on-top, click-through window drawn directly over the
game:

- A **green box** over every detected ball, labeled with its **track ID**.
- A **yellow line** from the cursor to the locked ball, boxed in yellow and
  labeled `LOCK <id>`. The yellow box marks the target the aim system would
  move to and click.

The track IDs let you watch the lock-on behavior: the locked ID stays put while
that ball is visible, and only moves to another when the locked one is hit or
disappears.

It is click-through, so it never steals mouse input from the game. It is purely
visual and sends nothing to the plotter.

**Aim Labs must run in windowed or borderless mode.** Exclusive fullscreen
cannot be drawn over by any external overlay. Windows only (uses tkinter +
ctypes).

## Run

From the `mm6000/` project root:

```bash
python overlay_debug/overlay.py
```

Press `q` to quit (works anywhere, via a global key listener).

## HSV tuner (test + calibrate detection)

Interactive trackbars to dial in `hsv_lower` / `hsv_upper` / `min_area_px`
for your monitor and Aim Labs blue. Shows detections and the binary mask
side by side.

```bash
python overlay_debug/tune_hsv.py            # live screen
python overlay_debug/tune_hsv.py --image shot.png   # static image
```

Keys: `f` freeze/unfreeze, `s` save snapshot + print config values, `q` quit.

Workflow: open Aim Labs, drag sliders until only the balls show white in the
mask (and each gets a green circle, with `balls: N` matching what you see),
press `s`, paste the printed three lines into `aimplotter/config.py`.

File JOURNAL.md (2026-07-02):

# **Initial Research + Starting CAD**
**Hours Spent: 0.5**
**Date(s): 6/23/26**
The idea starts with creating my own xy plotter of sorts, however I am still deciding on how large I wanted to make it so I only made the edge that the rail slots into so far. 

While CAD-ing, I was looking at other opensource designs as well as researching the exact model of rail/pulley system I wanted to use and decided on the MGN12H 300mm and GT2 pulleys and belts. 

Next will most likely be adding the model of the rail and building the "x direction" pulley system.


# **Finish Edge and Start Central Plate**
**Hours Spent: 0.75**
**Date(s): 6/23/26**

It took a while to find some proper dimensions for the holes, partially because I was looking at the wrong linear rail, but I added the last part which was the screw hole to the edge which may or may not be adjusted.

Then, I began the central plate which the motors for both the x and y axes will be on. This means 2 sets of mounts for each of the stepper motors and another for the the “y axis” rail, and one more to mount onto the x axis block, all using m3 screws.

On top of that, I added m5 screw holes that will be for the idler gears of the x axis.

With two of the technically most complex parts finished, the next part should be the y axis block mount alongside the mouse clicker. I also lowk need to add mounts for the limit switches, but i lowk dont want to, maybe ill just glue em on.


# **Begin Final Assembly**
**Hours Spent: 3.75**
**Date(s): 6/27/26**

With some of the custom designed parts finished, I began to work on the final assembly for the CAD that combined my parts with some external models of the parts I planned to use.

I had lost around an hour and an half of work due to Lookout crashing without me knowing, but most of it was redone in order to create the 300mm rail with only the model of the 100mm rail online after the first one failed.

I put the rail on both edge pieces (including remaking one because I realized they were not symmetrical), added the central plate to the x axis block, added the stepper motors, added the G2 pulleys and idler pulleys for both axes, added the y axis rail, and made and added the idler pulley for the y axis. I also added the required screws and nuts.

This also includes many smaller changes such as struggling and adjusting the screw positions, changing distances of screw holes on the central plate, changing the mount side of the y axis stepper motor, and many other small size revisions.

To Do List:
-   Create the Y axis mount
-   Add the belts
-   Add a rail parallel to the x axis for better stability
-   Add a mount for the Arduino Uno
-   Create the wiring diagram
-   Code

I’ll hopefully update this list through the final logs over the next few days.




# _Quick Fixes + Parallel Rail_
**Hours Spent: 0.75**
**Date(s): 6/28/26**

Made some quick fixes in positioning of the outlets for the stepper motors.

Then began working on the parallel rail for the x axis. I had to delete the previous end piece for the y axis to do so. It had a few problems in alignment of the 2 pulleys, but it should be accurate now.

To Do List:
-   Create the Y axis mount
-   Add the belts
-   ~~Add a rail parallel to the x axis for better stability~~
-   (New) Remake the edge pieces so it connects to a proper square mount for stability
-   Add a mount for the Arduino Uno
-   Create the wiring diagram
-   Code


# _Begin Working on & Finish Code (For Now)_
**Hours Spent: 3**
**Date(s): 6/29/26**

After working on the CAD for so long, I decided to begin working on the actual object detection and gcode generation portion that will be running this build. 

Currently, all I am training this for is to work in AimLabs, as it is very easy to create a model to aim at targets because of their distinctive neon blue hue as it only needs to detect colors and not full objects. After taking pre-existing detection projects and tweaking them to my use case, I had a passable detection that worked in AimLabs and could detect the correct blue color/target and the closest one. 

For the gcode, that would go into GRBL that will run on the Arduino Uno with a CNC Shield V3, I had to similarly take some inspiration from the internet. Because the very crucial information of mm per step was missing, which I cannot reliably obtain until the build is finished, I had to leave the code very generic for the time being, which means I will need to update it after building.

Claude Code was used to help bug fix and make sure I was not going insane.

To Do List:
-   Create the Y axis mount
-   Add the belts
-   Remake the edge pieces so it connects to a proper square mount for stability
-   Add a mount for the Arduino Uno
-   Create the wiring diagram
-   ~~Code~~
mm6 detection code

# _Finish CAD_
**Hours Spent: 5.5**
**Date(s): 6/30/26 - 7/1/26**

With the CAD being my largest obstacle to be completed with the design, I decided to complete it all.

First, I made the Y Axis Mount that would be holding the mouse itself to move alongside the plotter. The actual holder for the mouse was very simple, taking my mouse (the Razer Deathadder Essential) as the reference, I added a small box that would hold the mouse with less than 1 mm tolerance of extra space. This keeps the mechanical failure risk to a minimum while also being very efficient for the simple task. I also decided to add a SG90 servo onto the bottom of the mount that would be clicking the left click button.

Next, I decided to remake the mounts for the linear rails as they were very inefficient after adding the parallel x rail. Following research from several other plotter/xy designs, I made rectangular mounts with a threaded rod between them in order to secure the entire build together. I also added 2 triangular mounts to each side which I will add rubber feet to as well to prevent shaking from the plotter movement. I also made them thicker than in the previous designs.

Then, I added belts to the X and Y axes. The Y axis was simple after a bit of error with the placement of the idler pulley. However, the X axis was a bit trickier. Because I had to snake the belt between 2 idler pulleys, but I added it eventually which took me a bit longer. 

For the Arduino mount, I realized the most difficult part of the location would be the wiring to the servo, but even that was pretty trivial so the location was not an issue. For ease of use and removal, I just put it in a box on one of the ends.

The reason this section took a lot longer than the rest was the constant smaller problems I ran into and a lot of prototyping and deciding how/why I wanted to place an object and then actually doing it for several prototypes.

To Do List:
-   ~~Create the Y axis mount~~
-   ~~Add the belts~~
-   ~~Remake the edge pieces so it connects to a proper square mount for stability~~
-   ~~Add a mount for the Arduino Uno~~
-   Create the wiring diagram
-   (New) Create Journal and readme
mm6 image 1

# _Final Touches_
**Hours Spent: 1.25**
**Date(s): 7/1/26 - 7/2/26**

With the CAD done, I just began to prep and create my repo before I submit. 

The electrical diagram was very simple, and I made it in MS paint because the different softwares I tried were very annoying. Because there are not too many components though, I believe it turned out alright.

The journal and readme files took the longest because they were hand-typed (no ai). Lookout conked on me 2 times so I gave up on it, but I could still copy around half the work from the Stardance project. 
mm6000 wiring diagram

# _Overall_
**Time Spent: 15.5 hours**

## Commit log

2026-06-29 feat: PD/PID controller and hitbox check
2026-06-29 feat: GRBL serial plotter driver with soft limits and click
2026-06-29 feat: drift corrector reclaims travel during dead time
    [drift.py]
2026-06-29 feat: main loop, kill-switch, dry-run, integration test
2026-06-29 feat: interactive gain calibration script
2026-06-29 fix: address final review (servo release on kill, control-law units, GRBL handshake, soft-limit warning, calibrate return, detector dtype)
    [calibrate.py, controller.py, detector.py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]
2026-06-29 Add interactive HSV tuner for detection calibration
2026-06-29 feat: frame-to-frame target tracking with stable IDs
    Greedy nearest matching + lost-frame grace (Tracker, select_locked).
    Wired into run_loop (opt-in via tracker=) and cursor_demo. Lock holds
    only while the ball is seen this frame, so it never aims at a coasting ghost.
2026-06-29 feat: dxcam capture backend with mss fallback (config flag)
    make_capture() picks dxcam when available, else mss. Faster grabs via
    DirectX desktop duplication. Wired into main, cursor_demo, tuner.
2026-06-29 feat: show track IDs and lock-on in overlay
    Each box labeled with its stable track id, coasting tracks gray (lost),
    locked target highlighted yellow with LOCK label. Removed dead helper.
2026-07-02 add 3DP files
    [Triangle Bracket.step, XY Plotter Central Plate.step, XY Plotter Left Edge.step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]
2026-07-03 Add f3d files
    [Triangle Bracket.f3d, Triangle Bracket.step, XY Plotter Central Plate.f3d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]
2026-07-11 docs: design for direct stepper driver replacing GRBL
2026-07-11 docs: implementation plan for direct stepper driver
2026-07-11 feat: config servo angles replace GRBL M-code strings
    [config.py]
2026-07-11 feat: Arduino direct stepper+servo firmware, serial protocol
2026-07-11 fix: parse J/S args with strtod/atoi (avr sscanf %f unsupported)
    [mm6000.ino]
2026-07-11 feat: StepperPlotter driver for custom firmware protocol
2026-07-11 feat: wire StepperPlotter into main loop
2026-07-12 feat: calibrate.py uses StepperPlotter
2026-07-12 chore: dry-run print uses firmware protocol, not GRBL G-code
2026-07-12 chore: fix stale dry-run help text, add reset_input_buffer to calibrate
    Final-review minors A and C.
    [calibrate.py, main.py]
2026-07-12 docs: velocity-based smooth movement design spec
2026-07-12 docs: velocity smooth movement implementation plan
2026-07-12 feat: add velocity-control config fields
2026-07-12 feat: VelocityController maps error + feedforward to mm/s
    [velocity_controller.py]
2026-07-12 feat: VelocityPlotter streams non-blocking V setpoints
2026-07-12 feat: velocity_main streams setpoints with no settle stall
    [velocity_main.py]
2026-07-12 feat: velocity firmware with slew, watchdog, soft limits
2026-07-12 fix: reset feedforward on locked-target switch to prevent lurch
    [velocity_main.py]
2026-07-12 feat: tune velocity aim system and wire config foundation
    Disable feedforward (kff=0) — at ~140fps it amplified sub-pixel
    detection noise into large phantom velocities. Raise kp_v to 0.8 for
    snappier convergence, max_speed to 120 mm/s. Firmware ACCEL 4000 (smooth
    ramp without jerk), watchdog 600ms to cover the frame loop. Add dt to the
    debug line. Commit the config foundation (invert axes, gain, servo/port)
    the velocity loop depends on.
    [config.py, mm6000_velocity.ino, velocity_main.py]
2026-07-12 refactor: archive old stop-start driver for reference
    Move the superseded position-based move-and-settle driver out of the
    active tree into archive/stop-start-driver/: mm6000.ino firmware,
    StepperPlotter, main.py, calibrate.py, and their tests. The velocity
    streaming system is now the only active driver. Add a README explaining
    what it was and how to run it again.
2026-07-12 feat: velocity-native gain calibration + fresh-machine setup docs
    Add velocity_calibrate.py: measures gain (mm/px) by commanding a known
    velocity for a known time and measuring the pixel shift, so no firmware
    swap is needed (the velocity firmware only speaks V/S/!). Rewrite the
    readme's stale GRBL description to the velocity system and add a Setup &
    Run section covering flashing, deps, config, calibration, and tuning.
    [velocity_calibrate.py]
